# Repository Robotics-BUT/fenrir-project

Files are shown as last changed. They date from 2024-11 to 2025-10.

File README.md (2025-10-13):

# Fenrir Project - Universal Robotic Platform

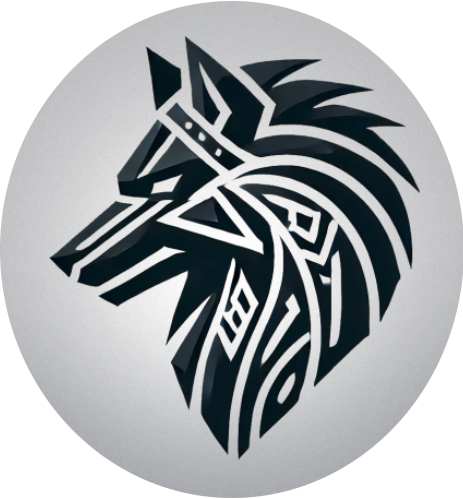
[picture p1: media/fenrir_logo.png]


The Fenrir Project is an open source of a multi purpose education robot dedicated for wide range of applications and usage in high-schools and universities.

The robot is based on Raspberry Pi 4 and Arduino Nano. The Raspberry Pi provides computational power, ROS2 support, WiFi connection and USB support. The Arduino Nano extends the PRi IOs and handles peripherals.

The development is currently still under development

## Robot Overview

### Robot visualization 

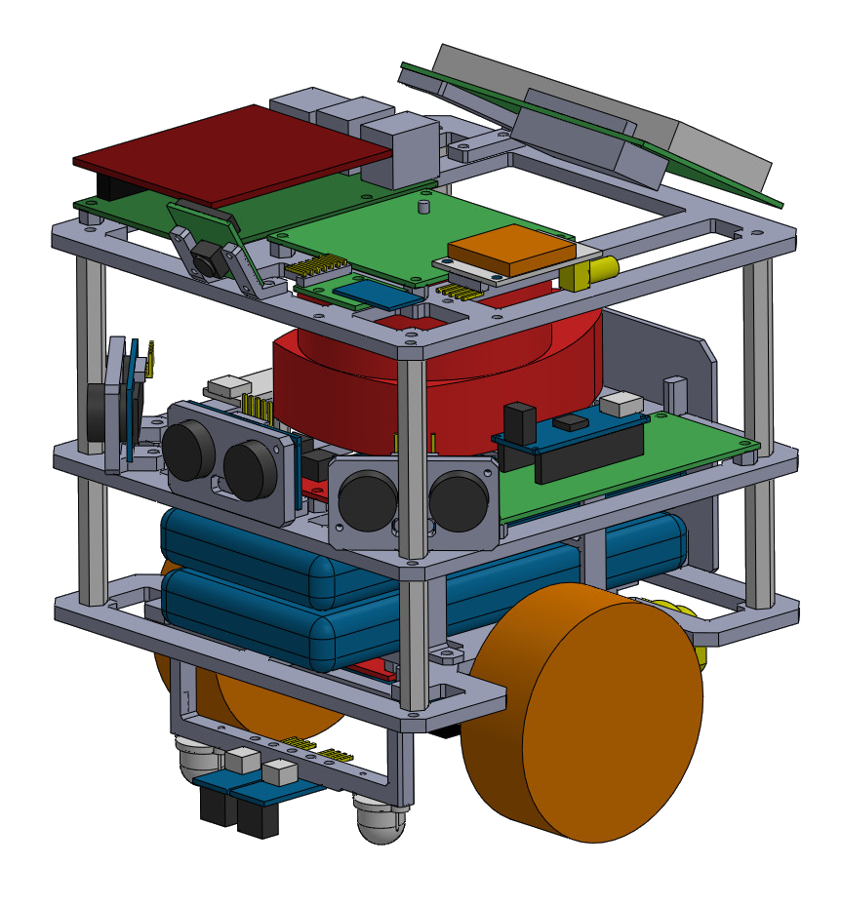
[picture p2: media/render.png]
Robot


### Overview schematic

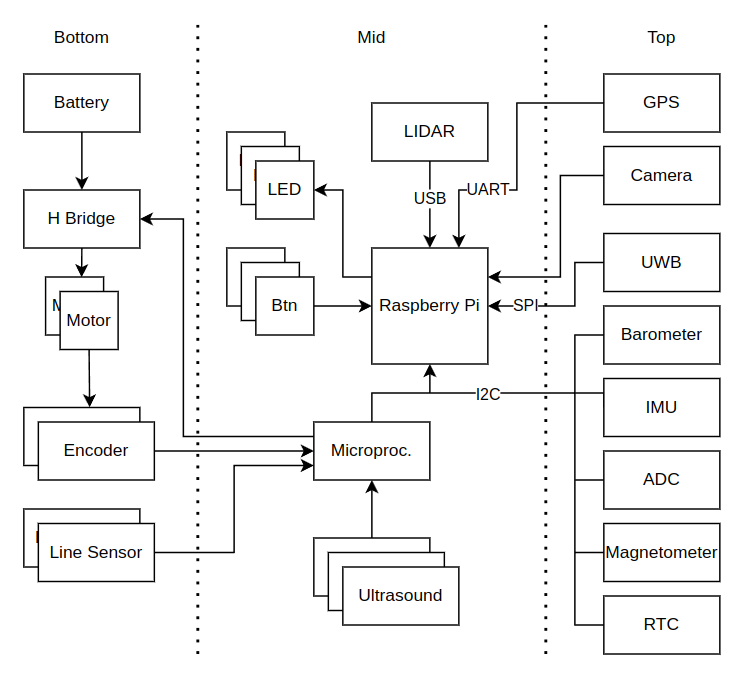
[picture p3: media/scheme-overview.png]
Overview schematic


### Power supply schematic

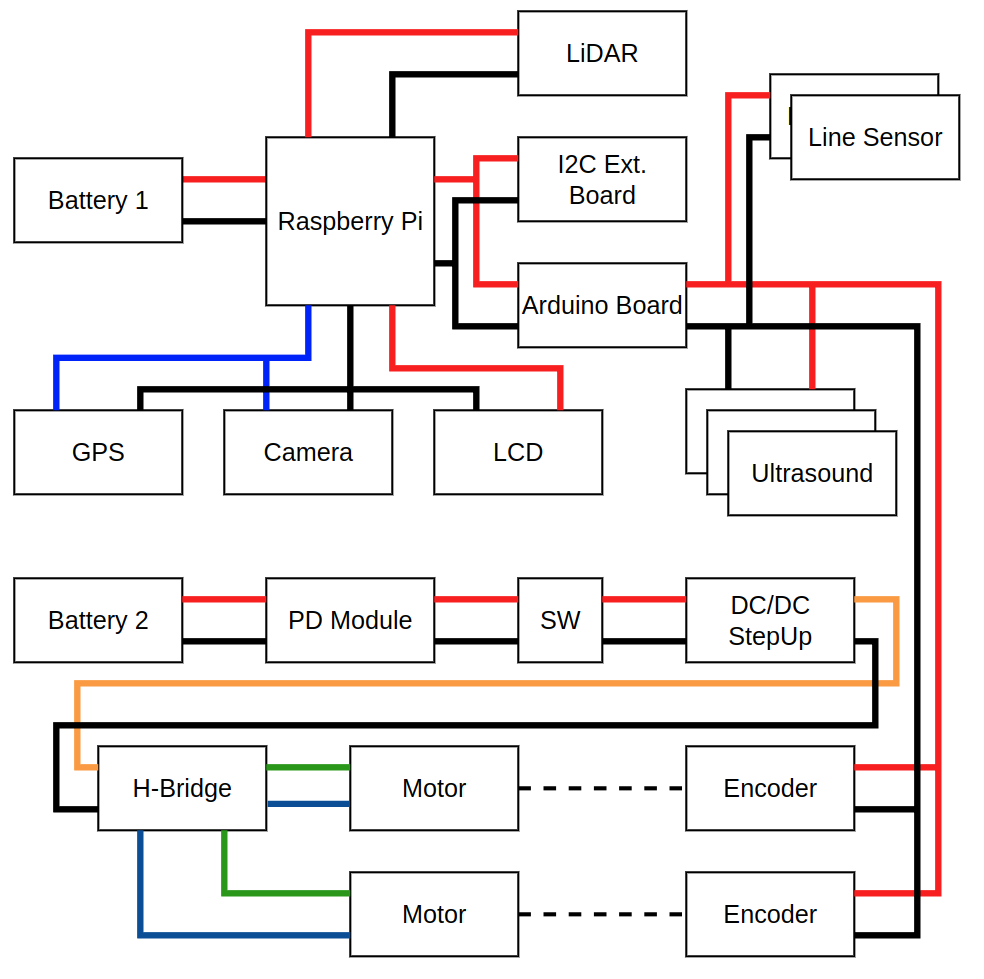
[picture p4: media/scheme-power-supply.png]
Power supply schematic


### Wiring Overview

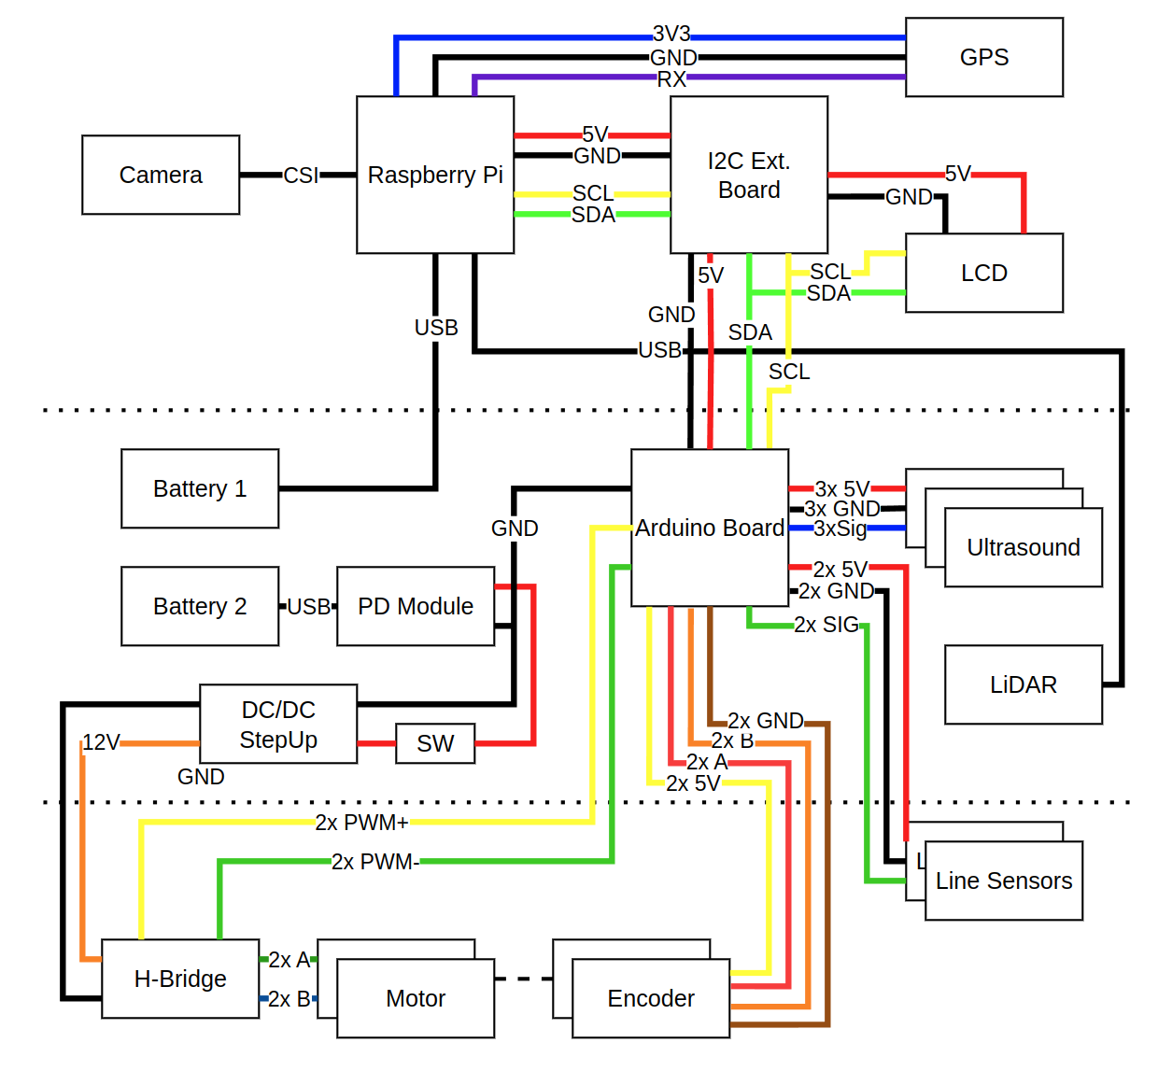
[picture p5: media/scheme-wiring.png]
Wiring Overview


**Note**: The sensors numbering goes from left to right
 - Ultrasound 1 - left, Ultrasound 2 - center, Ultrasound 3 - right
 - Line sensor 1 - left, Line sensor 2 - right
 - Motor 1 - left, Motor 2 - right
 - Encoder 1 - left, Encoder 2 - right

| **Module A** | **Pin**  | **Module B** | **Pin** | **Type** | **Length** | **Note** |
|---|---|---|---|---|---|---|
| Battery 1 | - | PD Module | - | USB-C - USB-C | 15cm | - |
| Battery 2 | - | Raspberry Pi | - | USB-C - USB-C | 15cm | - |
| Raspberry Pi | - | Camera | - | CSI Cable | 10cm | - |
| Raspberry Pi | 3v3 | GPS | VCC | wire (blue) | 10cm | 3V3 |
| Raspberry Pi | GND | GPS | GND | wire (black) | 10cm | GND |
| Raspberry Pi | Rx | GPS | TxD | wire (purple) | 10cm | UART |
| Raspberry Pi | 5V | I2C Board | 5V | wire (red) | 8cm | 5V |
| Raspberry Pi | GND | I2C Board | GND | wire (black) | 8cm | GND |
| Raspberry Pi | SCL | I2C Board | SCL | wire (yellow) | 8cm | SCL |
| Raspberry Pi | SDA | I2C Board | SDA | wire (green) | 8cm | SDA |
| Raspberry Pi | - | LIDAR | - | USB-A - microUSB | 10cm | - |
| I2C Board | 5V | LCD | VCC | wire (red) | 8cm | 5V |
| I2C Board | GND | LCD | GND | wire (black) | 8cm | GND |
| I2C Board | SCL | LCD | SCL | wire (yellow) | 8cm | SCL |
| I2C Board | SDA | LCD | SDA | wire (green) | 8cm | SDA |
| I2C Board | 5V | Arduino | VCC | wire (red) | 15cm | 5V |
| I2C Board | GND | Arduino | GND | wire (black) | 15cm | GND |
| I2C Board | SCL | Arduino | SCL | wire (yellow) | 15cm | SCL |
| I2C Board | SDA | Arduino | SDA | wire (green) | 15cm | SDA |
| Arduino | US1 | Ultrasound 1 | Vcc | wire (red) | 10cm | 5V |
| Arduino | US1 | Ultrasound 1 | GND | wire (black) | 10cm | GND |
| Arduino | US1 | Ultrasound 1 | Echo/Trig | wire (blue) | 10cm | signal |
| Arduino | US2 | Ultrasound 2 | Vcc | wire (red) | 10cm | 5V |
| Arduino | US2 | Ultrasound 2 | GND | wire (black) | 10cm | GND |
| Arduino | US2 | Ultrasound 2 | Echo/Trig | wire (blue) | 10cm | signal |
| Arduino | US3 | Ultrasound 3 | Vcc | wire (red) | 15cm | 5V |
| Arduino | US3 | Ultrasound 3 | GND | wire (black) | 15cm | GND |
| Arduino | US3 | Ultrasound 3 | Echo/Trig | wire (blue) | 15cm | signal |
| Arduino | Line1 | Line Sens. 1 | VCC | wire (red) | 15cm | 5V |
| Arduino | Line1 | Line Sens. 1 | GND | wire (black) | 15cm | GND |
| Arduino | Line1 | Line Sens. 1 | A0 | wire (blue) | 15cm | signal |
| Arduino | Line2 | Line Sens. 2 | VCC | wire (red) | 15cm | 5V |
| Arduino | Line2 | Line Sens. 2 | GND | wire (black) | 15cm | GND |
| Arduino | Line2 | Line Sens. 2 | A0 | wire (blue) | 15cm | signal |
| Arduino | 5V | Encoder 1 | - | wire (yellow) | 20cm | 5V |
| Arduino | GND | Encoder 1 | - | wire (brown) | 20cm | GND |
| Arduino | EN1A | Encoder 1 | - | wire (red) | 20cm | A |
| Arduino | EN1B | Encoder 1 | - | wire (orange) | 20cm | B |
| Arduino | 5V | Encoder 2 | - | wire (yellow) | 20cm | 5V |
| Arduino | GND | Encoder 2 | - | wire (brown) | 20cm | GND |
| Arduino | EN2A | Encoder 2 | - | wire (red) | 20cm | A |
| Arduino | EN2B | Encoder 2 | - | wire (orange) | 20cm | B |
| Arduino | GND | PD Module | OUT- | wire (black) | - | - |
| Arduino | M1A | H-Bridge | IN3 | wire (yellow) | 20cm | PWM A+ |
| Arduino | M1B | H-Bridge | IN4 | wire (green) | 20cm | PWM A- |
| Arduino | M2A | H-Bridge | IN1 | wire (yellow) | 20cm | PWM B+ |
| Arduino | M2B | H-Bridge | IN2 | wire (green) | 20cm | PWM B- |
| PD Module | + | H-Bridge | +12V | wire (orange) | 15cm | 12V |
| PD Module | - | H-Bridge | GND | wire (black) | 15cm | GND |
| H-Bridge | OUT1+ | Motor 1 | - | wire (green) | 20cm | + |
| H-Bridge | OUT1- | Motor 1 | - | wire (blue) | 20cm | - |
| H-Bridge | OUT2+ | Motor 2 | - | wire (green) | 20cm | + |
| H-Bridge | OUT2- | Motor 2 | - | wire (blue) | 20cm | - |

## Equipment

| Role | Component | URL |
|---|---|---|
| Main Computer | RPi | [link](https://cz.mouser.com/ProductDetail/Raspberry-Pi/SC01959?qs=T%252BzbugeAwjhNCW2QVhlotw%3D%3D) |
| Helper Microcontroller | Arduino Nano | [link](https://www.laskakit.cz/arduino-nano-r3--atmega328p-klon--pripajene-piny/) |
| 2x Battery | Powerbank 10000 mAh | [link](https://www.alza.cz/alzapower-parade-power-delivery?dq=7177723) |
| Camera | RPi Camera v2 | [link](https://rpishop.cz/mipi-kamerove-moduly/329-raspberry-pi-kamera-modul-v2.html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) |
| GPS | NEO-7M module | [link](https://dratek.cz/arduino/1733-gps-satelitni-urceni-polohy-neo-7m-modul.html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) |
| 2D LiDAR | RPLiDAR A1M8 | [link](https://rpishop.cz/lidary/1631-rplidar-a1m8-360stupnovy-laserovy-scanner-kit-dosah-12m.html) |
| LCD | HD44780 20x4 I2C | [link](https://dratek.cz/arduino/1421-eses-i2c-20x4-display-pro-jednodeskove-pocitace.html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) |
| 3x Ultrasound | SRF-05 | [link](https://dratek.cz/arduino/1735-meric-vzdalenosti-ultrazvukovy-5pin-hy-srf05-pro-arduino.html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) |
| 2x Line Sensor | TCRT5000 module | [link](https://www.laskakit.cz/arduino-infracerveny-senzor-sledovani-cary-s-lm393/) |
| H Bridge | L298N module | [link](https://www.laskakit.cz/h-mustek-pro-krokovy-motor-l298n--dualni-motorovy-modul/) |
| Motor with Encoder | DG01D‐E | [link](https://cz.mouser.com/ProductDetail/SparkFun/ROB-16413?qs=vmHwEFxEFR%2F20T1Ah9zr5w%3D%3D) |
| IMU | MPU6050 | [link](https://pajenicko.cz/gyroskop-akcelerometr-gy-521-s-mpu6050-i2c) |
| Barometer | BME280 | [link](https://pajenicko.cz/senzor-na-mereni-teploty-vlhkosti-tlaku-bme280) |
| Real Time Clock | DS3231 | [link](https://www.laskakit.cz/arduino-rtc-hodiny-realneho-casu-ds3231-at24c32/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) |
| ADC | ADS1115 | [link](https://pajenicko.cz/ad-prevodnik-ads1115-s-programovatelnym-zesilenim-16bit-4-kanaly-i2c-rozhrani) |
| UWB (not yet) | DWM1000 | [link](https://www.laskakit.cz/decawave-dwm1000-lokalizacni-modul/) |
| DC/DC Step Up | XL6009 | [link](https://www.laskakit.cz/step-up-boost-menic-s-xl6009--cervena/) |
| Power Delivery | USB-C PD module | [link](https://www.laskakit.cz/usb-c-pd-qc-prepinac-napajeciho-napeti/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) |
| Switch | | [link](https://pajenicko.cz/kulaty-kolebkovy-spinac-se-zelenou-led-12v-20a) |

## Acknowledgments

This work was created with the support of project RP182401001 under the PPSŘ 2025 program.

## Authors

Adam Ligocki - adam.ligocki@vut.cz

Petr Šopák - petr.sopak@vut.cz

Jakum Minařík

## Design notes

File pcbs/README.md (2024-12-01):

# Fenrir Project - PCBs

### RPi Ext Board

Schema

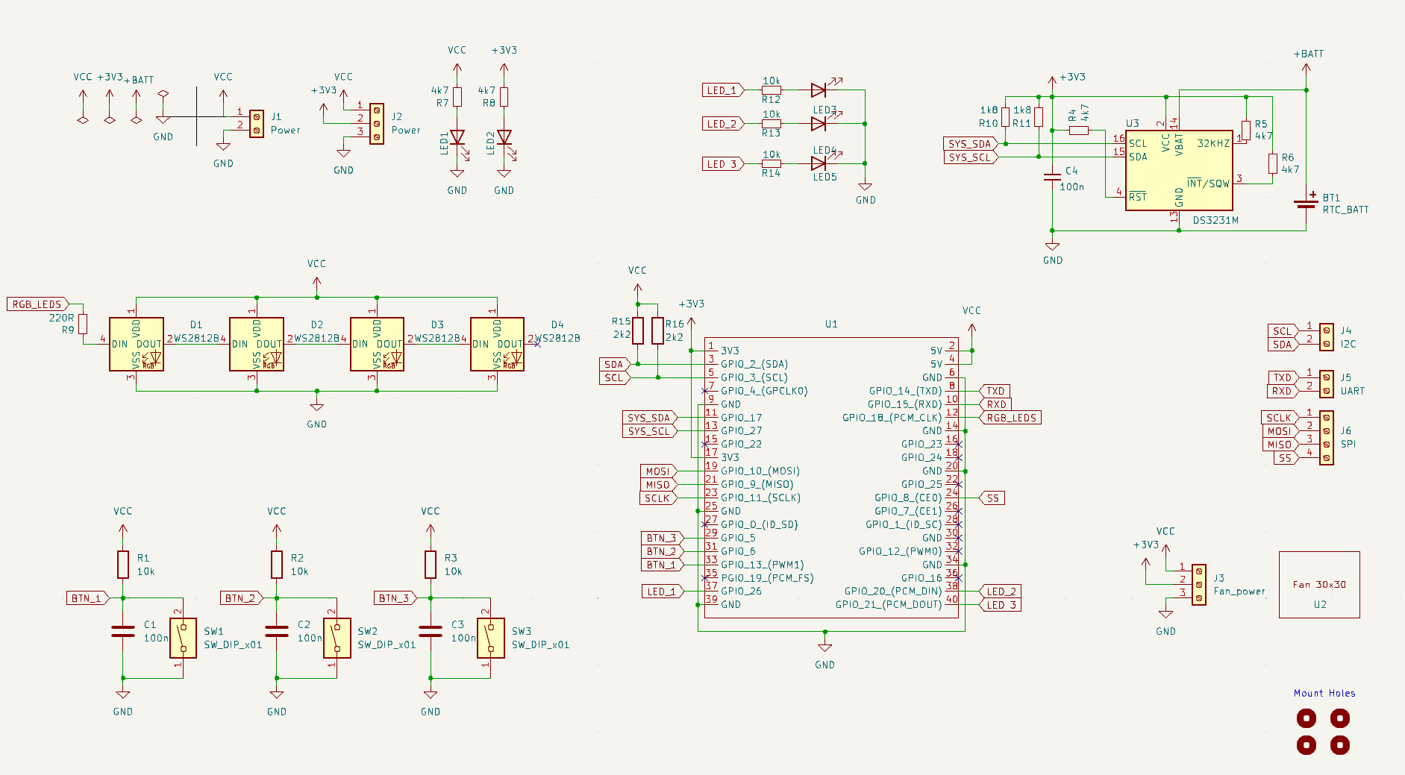
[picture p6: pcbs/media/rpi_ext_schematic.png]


Render Top

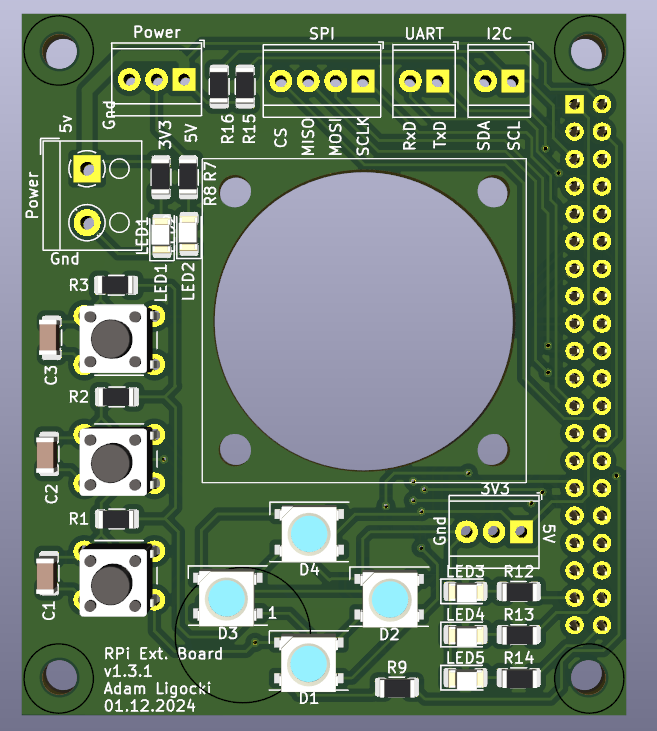
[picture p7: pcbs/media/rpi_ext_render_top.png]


Render Bot

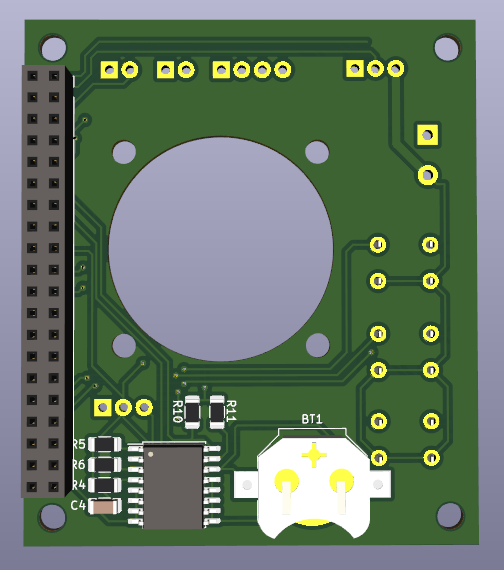
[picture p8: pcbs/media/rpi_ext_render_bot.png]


### Arduino Board

Schema

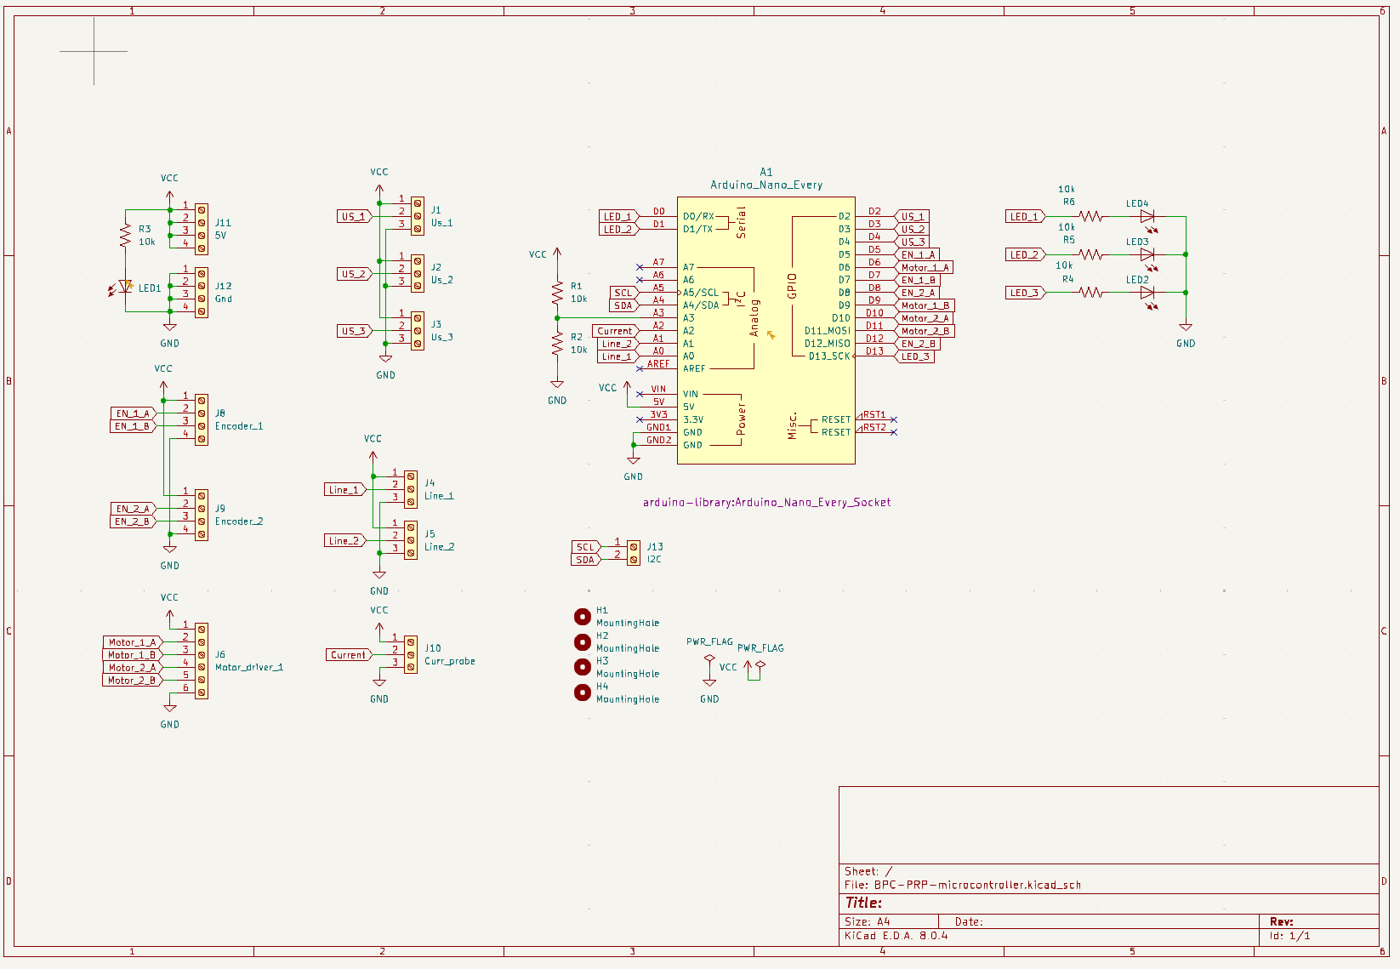
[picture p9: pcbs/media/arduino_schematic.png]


Render Top

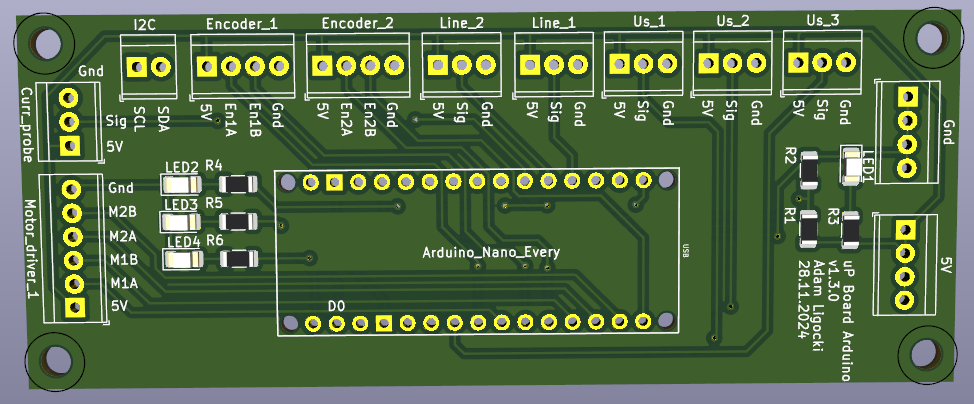
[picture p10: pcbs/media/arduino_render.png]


### I2C Board

Schema

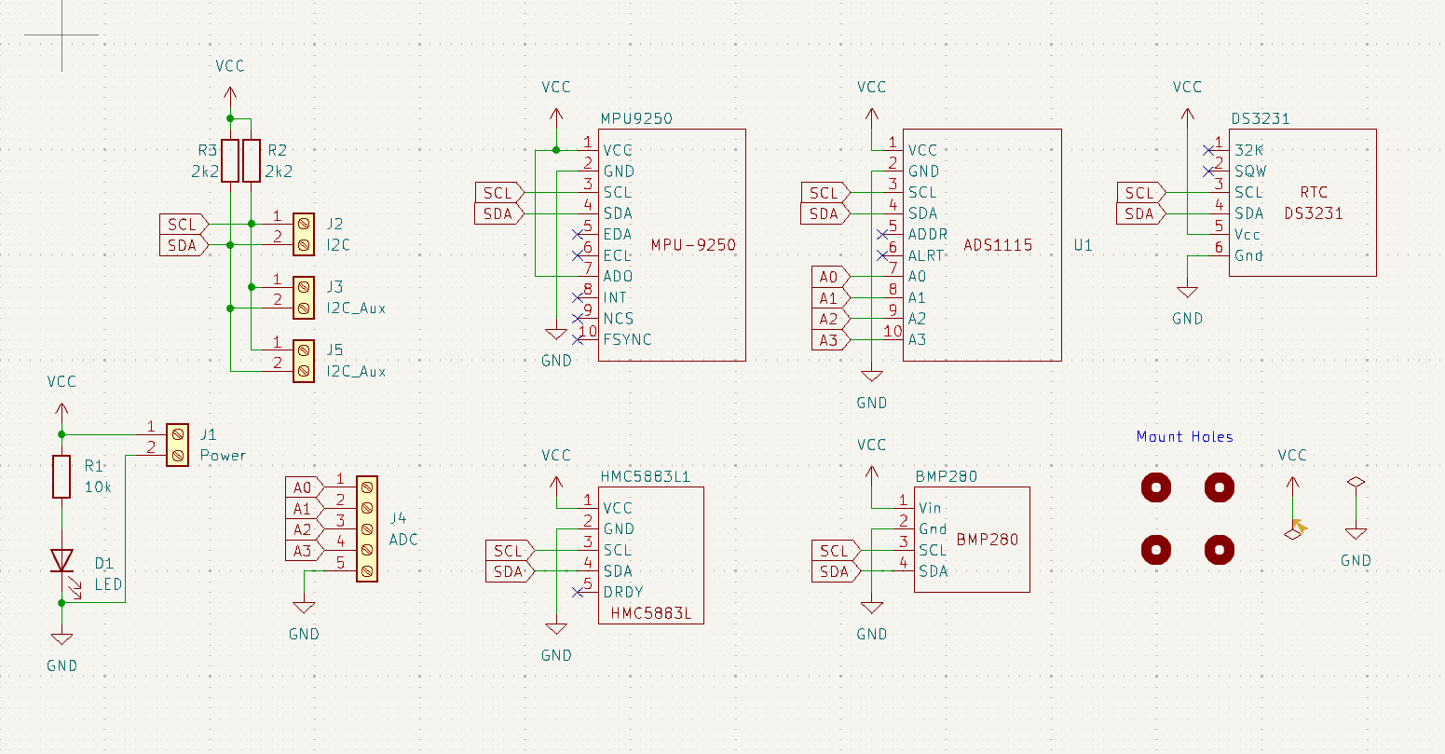
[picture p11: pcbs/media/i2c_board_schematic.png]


Render Top

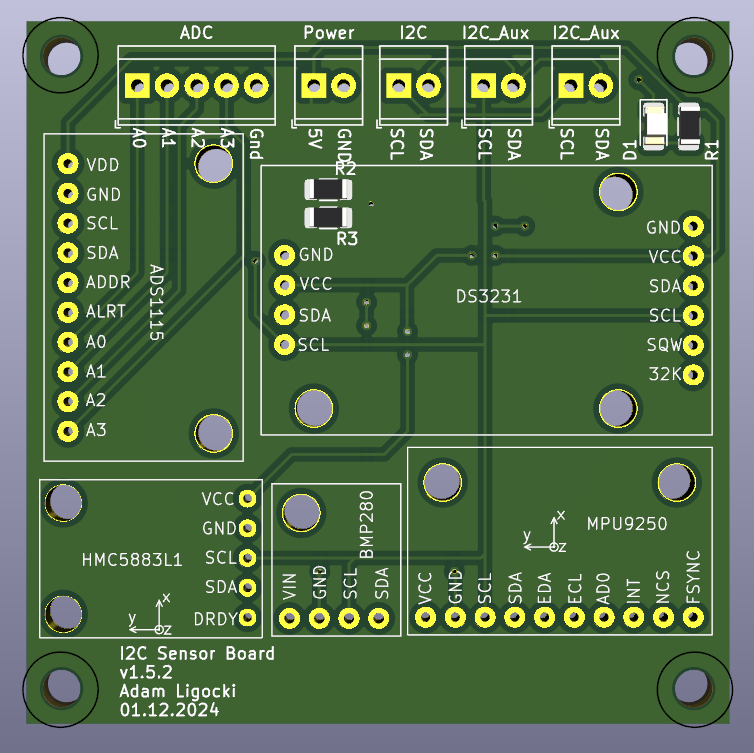
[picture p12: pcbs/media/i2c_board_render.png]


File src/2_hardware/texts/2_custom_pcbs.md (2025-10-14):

# Custom PCBs

This chapter presents the custom PCBs designed for the Fenrir Project.

The robot includes **three custom PCBs** with the following functionalities:

 - **Raspberry Pi Sield (header)**
   - Power supply
   - I2C bus
   - SPI bus
   - UART bus
   - Fan cooling
   - Buttons
   - LEDs

 - **I2C Sensor Board**
   - IMU (Accelerometer + Gyroscope)
   - Barometer
   - Magnetometer
   - ADC
   - Real-Time Clock (RTC)

 - **Arduino Nano Board**
   - I2C bus
   - Motor Control
   - Motor Encoders
   - Ultrasonic Sensors
   - Line Sensors

For detailed design files, please refer to the [`pcbs folder`](/pcbs) in the root of this repository.

------------------------------------------------------------------------------------------------------------
### Raspberry Pi Shield

<p id="rpi_ext_schematic" align="center">
  ext_schematic
</p align="center">
<p align="center"><em>Figure 1. Raspberry Pi Shield schematic.</em></p>

<p id="rpi_ext_render_top" align="center">
  rpi_ext_render_top
</p align="center">
<p align="center"><em>Figure 2. Raspberry Pi Shield 3D render.</em></p>

### I2C Sensor Board

<p id="i2c_board_schematic" align="center">
  i2c_board_schematic
</p align="center">
<p align="center"><em>Figure 3. I2C Sensor Board schematic.</em></p>

<p id="i2c_board_render" align="center">
  i2c_board_render
</p align="center">
<p align="center"><em>Figure 4. I2C Sensor Board 3D render.</em></p>

### Arduino Nano Every Board

<p id="arduino_schematic" align="center">
  arduino_schematic
</p align="center">
<p align="center"><em>Figure 5. Arduino Nano Board schematic.</em></p>

<p id="arduino_render" align="center">
  arduino_render
</p align="center">
<p align="center"><em>Figure 6. Arduino Nano Board 3D render.</em></p>

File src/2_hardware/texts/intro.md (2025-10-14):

# Hardware Desing

This section provides a detailed description of all hardware components required to build the robot.  
It covers 3D-printed parts, electronic components, integrated modules, and custom-designed PCBs.

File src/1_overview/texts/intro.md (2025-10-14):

# Fenrir Project Overview

<p id="fenrir_logo" align="center">
  Fenrir Logo
</p align="center">

The **Fenrir Project** is an open-source, multi-purpose educational robot designed for a wide range of applications in high schools and universities.

The robot is based on *Raspberry Pi 4* and *Arduino Nano*. The Raspberry Pi provides computational power, ROS2 support, WiFi connection and USB support. The Arduino Nano extends the Raspberry Pi IOs and manages peripherals.

## Robot Overview

### Visualization - Physical Design

<p id="robot_renderer" align="center">
  robot renderer
</p align="center">

### Schematic system Architecture

<p id="overview_schematic" align="center">
  Overview schematic
</p align="center">

## Acknowledgments

This work was created with the support of project RP182401001 under the PPSŘ 2025 program.

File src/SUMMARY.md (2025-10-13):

[Introduction](title-page.md)

- [Fenrir Project Overview](1_overview/texts/intro.md)
- [Hardware Design](2_hardware/texts/intro.md)
  - [3D Print](2_hardware/texts/1_3d_print.md)
  - [Custom PCBs](2_hardware/texts/2_custom_pcbs.md)
  - [Modules](2_hardware/texts/3_modules.md)
  - [Wiring](2_hardware/texts/4_wirings.md)
  - [Bill of Materials](2_hardware/texts/5_bom.md)
- [Software Architecture](3_software/texts/intro.md)
  - [Raspberry Pi Software](3_software/texts/1_rpi_sw.md)
  - [Arduino Firmware](3_software/texts/2_arduino_fw.md)
- [Robot Assembly](4_assembly/texts/intro.md)
    - [Assembly - step by step](4_assembly/texts/assembly.md)
- [SW Installation and Setup](5_setup/texts/intro.md)
    - [Raspberry Pi Installation](5_setup/texts/1_rpi.md)
    - [Arduino Programming](5_setup/texts/2_arduino.md)

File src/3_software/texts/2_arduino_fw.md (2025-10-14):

# Arduino Firmware

The firmware is available here Firmware.

This Arduino Nano program works as a motor controller that talks with a main computer (for example a Raspberry Pi) using I2C communication. The Nano is an I2C slave – it waits for messages from the master and answers when needed. When the master sends data, the Nano updates target speeds or control settings. When the master asks for data, the Nano sends back measurements like encoder counts or wheel speeds. This communication happens using interrupt callbacks, so it does not stop the main program loop. In this way, the Nano can control motors and communicate at the same time.

Arduino handles the ultrasound sensors, line sensors, possible extension for current sensor and controls the motors.

The robot wheels have encoders that measure how fast they rotate. Each encoder gives electrical pulses when the wheel moves. The Nano uses interrupts to count these pulses very quickly without missing them. The number of pulses in a short time tells how fast the wheel is turning. In the main loop, the program reads these counts and calculates the wheel speed. These measured speeds are compared with the target speeds received from the master to see if the motors are running correctly or need adjustment.

To keep the wheels turning at the right speed, the Nano uses a PID controller. In every cycle of the main loop, the program calculates the difference between target and actual speed and adjusts the motor power with PWM signals. The direction pins control forward or backward rotation, and the PWM value sets how strong the motor runs. The main loop repeats this many times per second, keeping the movement smooth and stable. Meanwhile, I2C and encoder interrupts work in the background, so the system always knows the latest speed and can react quickly to commands from the master.

## Memory Space

<div align = center>

| Byte | Value | Length | R/W |
|---|---|---|-----|
| 0 | ultrasound 0 distance [cm] | 1B | R |
| 1 | ultrasound 1 distance [cm] | 1B | R |
| 2 | ultrasound 2 distance [cm] | 1B | R |
| 3 | encoder A [-] | 4B | R |
| 7 | encoder B [-] | 4B | R |
| 11 | current probe [-] | 2B | R |
| 13 | line sensor 0 [-] | 2B | R |
| 15 | line sensor 1 [-] | 2B | R |
| 17 | motor 0 speed [-] | 2B | W |
| 18 | motor 1 speed [cm] | 1B | W |
| 19 | reserverd | 1B | - |

</div>

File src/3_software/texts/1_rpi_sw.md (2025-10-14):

# Raspberry Pi Software

This project runs on a Raspberry Pi (Ubuntu + ROS 2 Humble) and acts as the high-level HW wrapper of the robot. The Pi hosts ROS 2 nodes that handle lidar, camera, I2C sensors (and the Arduino), RGB LEDs, and buttons. In effect, it gathers all the sensory data, publish them via ROS 2 topics, which makes it easy to read and make decisions and later on it accepts topic for motor speeds.

For sensors, the Pi runs specialized ROS 2 nodes: one for the lidar to scan the environment, one for the camera to capture images or video, and drivers for I2C sensors (ADC, IMU, magnetometer, etc.) and the Arduino (which itself controls motors and encoders, line sensors and ultrasounds). There are also nodes (or scripts) to manage RGB LEDs (for status or feedback) and buttons (for user interaction or emergency stop). All sensor inputs are published into the ROS 2 ecosystem so other nodes (e.g. navigation, mapping, control) can subscribe and act on them.

In addition, the repository includes helper scripts for setting up the Raspberry Pi environment (installing required packages, configuring ROS 2, setting up node launch files, calibrations, etc.). These scripts make it easier to initialize a fresh Pi with all dependencies, and to launch the full ROS 2 system smoothly. So overall, the Raspberry Pi side is responsible for integrating sensors, executing high-level logic, and coordinating with the Arduino via I2C, all within the ROS 2 framework on Ubuntu.

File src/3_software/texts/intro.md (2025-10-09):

# Software Architecture

This chapter discusses software architecture of the Fenrir Robot.

The Raspberry Pi software and the Arduino firmware is described and the way how both systems communicate with each other.

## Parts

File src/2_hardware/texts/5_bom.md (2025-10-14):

# Bill of Materials

<div align="center">

| Role | Quantity | Price pre one | URL |
|---|---|---|---|
| RPi 4 4GB | 1 | 60 EUR | [link](https://cz.mouser.com/ProductDetail/Raspberry-Pi/SC01959?qs=T%252BzbugeAwjhNCW2QVhlotw%3D%3D) |
| RPLidar | 1 | 130 EUR | [link](https://rpishop.cz/lidary/1631-rplidar-a1m8-360stupnovy-laserovy-scanner-kit-dosah-12m.html) |
| SD Card 32GB | 1 | 12 EUR | [link](https://rpishop.cz/micro-sd/3132-raspberry-pi-32gb-microsdhc-class-10-uhs-i-u1-a1-s-raspberry-pi-os.html) |
| RPi Camera v2 | 1 | 18 EUR | [link](https://rpishop.cz/mipi-kamerove-moduly/329-raspberry-pi-kamera-modul-v2.html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) |
| RPi Cooling | 1 | 2 EUR | [link](https://rpishop.cz/pasivni/669-hlinikove-chladice-pro-raspberry-pi.html) |
| RPi Fan | 1 | 3 EUR | [link](https://rpishop.cz/aktivni/1644-vetrak-pro-raspberry-pi-30cm-kabel.html) |
| | | | |
| DC Motor | 2 | 12 EUR | [link](https://cz.mouser.com/ProductDetail/SparkFun/ROB-16413?qs=vmHwEFxEFR%2F20T1Ah9zr5w%3D%3D) |
| | | | |
| Arduino Every | 1 | 15 EUR | [link](https://www.laskakit.cz/arduino-nano-every--original/) |
| Line Sensor | 2 | 1 EUR | [link](https://www.laskakit.cz/arduino-infracerveny-senzor-sledovani-cary-s-lm393/) |
| H-Bridge | 1 | 2 EUR | [link](https://www.laskakit.cz/h-mustek-pro-krokovy-motor-l298n--dualni-motorovy-modul/) |
| MPU6500 | 1 | 3 EUR | [link](https://www.laskakit.cz/arduino-gyroskop-a-akcelerometr-gy-521--mpu6050/) |
| HMC5883L | 1 | 3 EUR | [link](https://www.laskakit.cz/3-osy-magnetometr-a-kompas-hmc5883l/) |
| DC/DC step up | 1 | 2 EUR | [link](https://dratek.cz/arduino/1752-boost-buck-step-up-down-modul-solarniho-napajeni-nastavitelny-dc-dc-xl6009.html) |
| SRF05 | 3 | 2 EUR | [link](https://dratek.cz/arduino/1735-meric-vzdalenosti-ultrazvukovy-5pin-hy-srf05-pro-arduino.html) |
| RTC | 1 | 4 EUR | [link](https://dratek.cz/arduino/1261-rtc-hodiny-realneho-casu-ds3231-at24c32-iic-pametovy-modul-pro-arduino.html) |
| ADS1115 | 1 | 15 EUR | [link](https://dratek.cz/arduino/2955-i2c-ad-prevodnik-ads1115-16-bit-adc-4-kanaly-s-programovatelnym-zesilenim.html) |
| BME280 | 1 | 8 EUR | [link](https://dratek.cz/arduino/1361-bme280-modul-mereni-teploty-vlhkosti-a-barometrickeho-tlaku-precizni.html) |
| | | | |
| USB PD Module | 1 | 2 EUR | [link](https://www.laskakit.cz/usb-c-pd-qc-prepinac-napajeciho-napeti/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) |
| | | | |
| LCD | | | |
| | | | |
| Screw terminal 2x 5.08 | 5 | 0.3 EUR | [link](https://www.laskakit.cz/sroubovaci-svorkovnice-do-dps-kf301-2p/) |
| Screw terminal 3x 2.54 | 8 | 0.3 EUR | [link](https://www.laskakit.cz/sroubovaci-svorkovnice-do-dps-kf128-2-54/?variantId=8868) |
| Screw terminal 2x 2.54 | 5 | 0.2 EUR | |
| | | | |
| GPS | 1 (optional) | 15 EUR | [link](https://dratek.cz/arduino-platforma/1733-gps-satelitni-urceni-polohy-neo-7m-modul.html) |
| DWM 1000 | 1 (optional) | 40 EUR | [link](https://cz.mouser.com/ProductDetail/Qorvo/DWM1000?qs=sGAEpiMZZMu3sxpa5v1qrrjDD2pjKdCcRPXEFIZh8rA%3D) |
| | | | |
| Powerbank | 2 | 20 EUR | [link](https://www.alza.cz/alzapower-parade-power-delivery?dq=7177721) |
| | | | |
| Caster | 3 | 3 EUR | [link](https://botland.store/reference-balls/137-ball-caster-12-metal-pololu-953-5903351240772.html) |
| | | | |
| Screw M3x6 | 44 | - | - |
| Screw M3x25 | 4 | - | - |
| | | | |
| Color Wires | - | - | - |
</div>

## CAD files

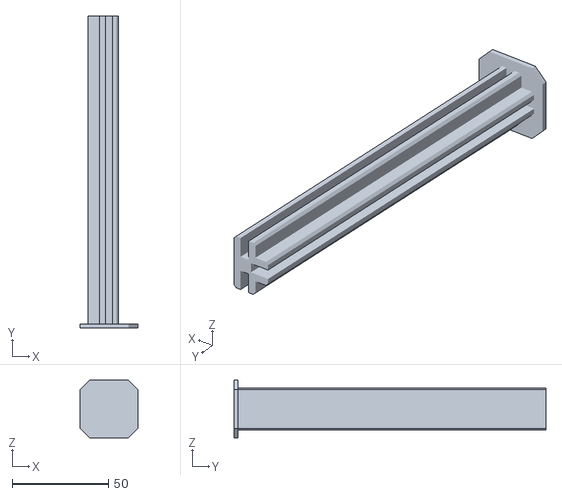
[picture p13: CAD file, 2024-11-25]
3d-print/maze/joint_3.STL
30.0 x 162.0 x 30.0

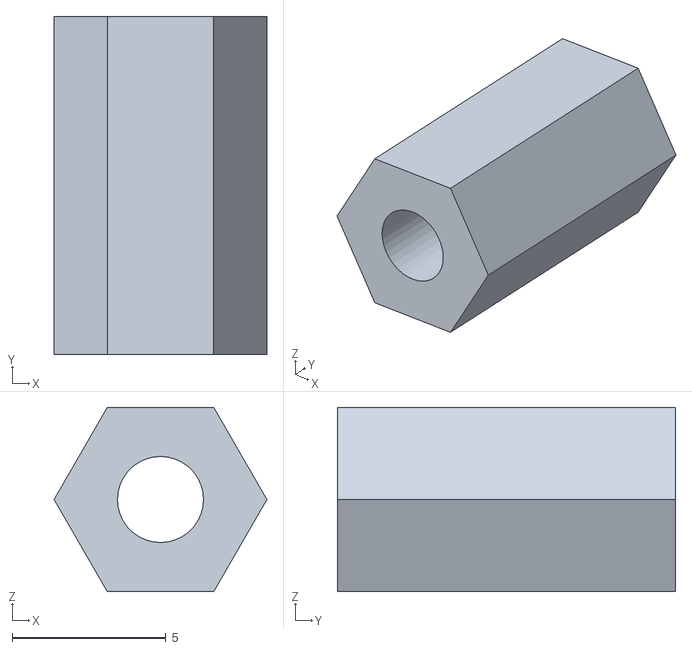
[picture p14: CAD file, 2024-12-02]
3d-print/robot/pillar.STL
6.93 x 11.0 x 6.00

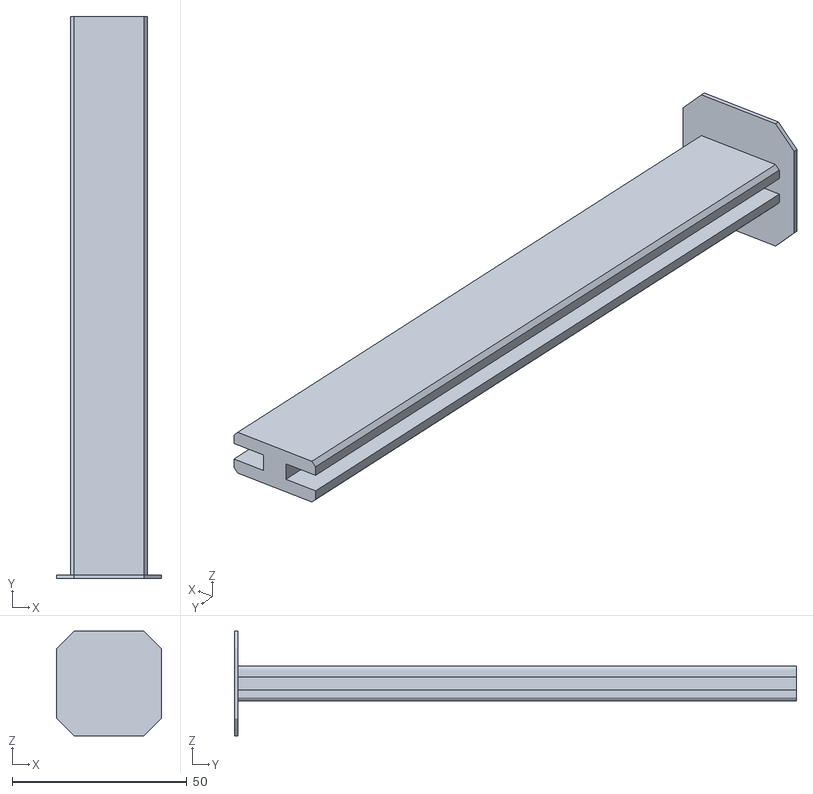
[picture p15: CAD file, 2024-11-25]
3d-print/maze/joint_2_180.STL
30.0 x 161.0 x 30.0

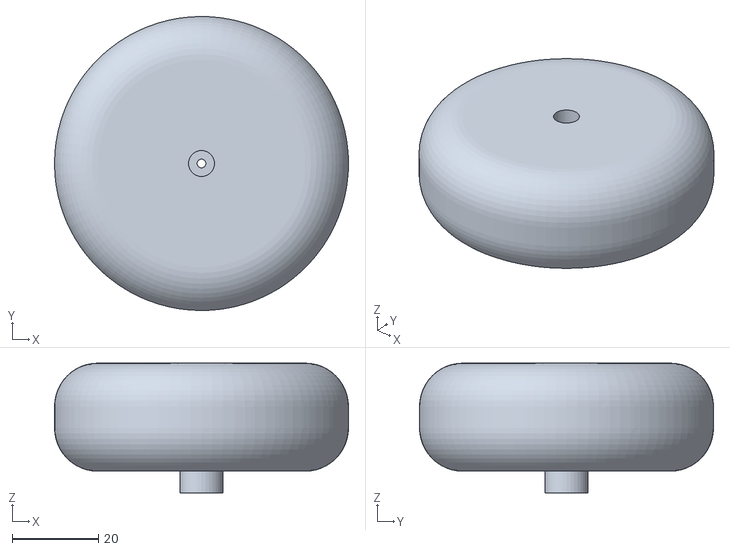
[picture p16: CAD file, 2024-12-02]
3d-print/robot/wheel.STL
68.0 x 68.0 x 30.0

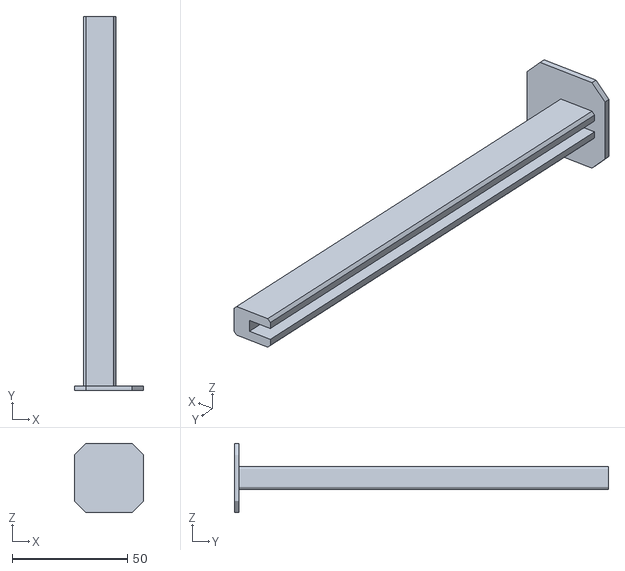
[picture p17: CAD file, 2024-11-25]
3d-print/maze/joint_1.STL
30.0 x 162.0 x 30.0

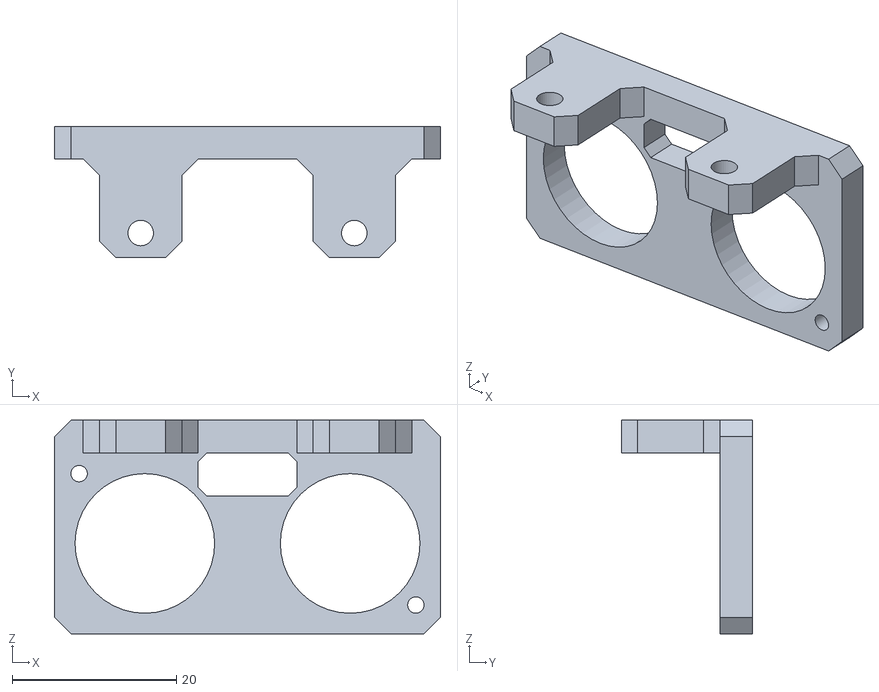
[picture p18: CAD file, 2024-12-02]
3d-print/robot/srf05_mount.STL
47.0 x 16.0 x 26.0

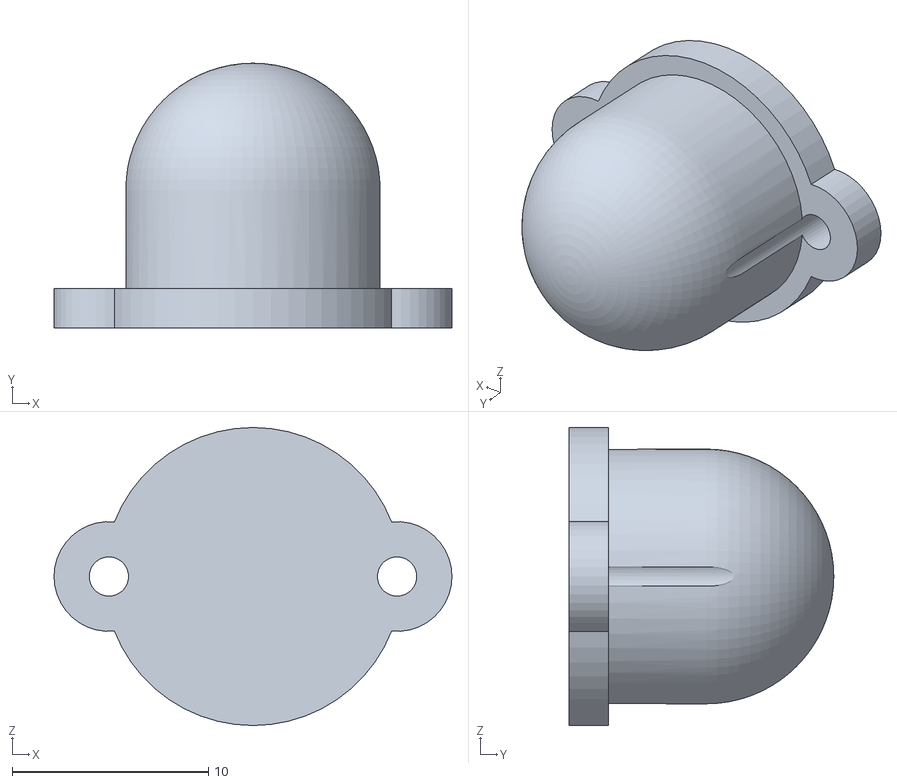
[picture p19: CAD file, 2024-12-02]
3d-print/robot/ball_2.STL
20.3 x 13.5 x 15.2

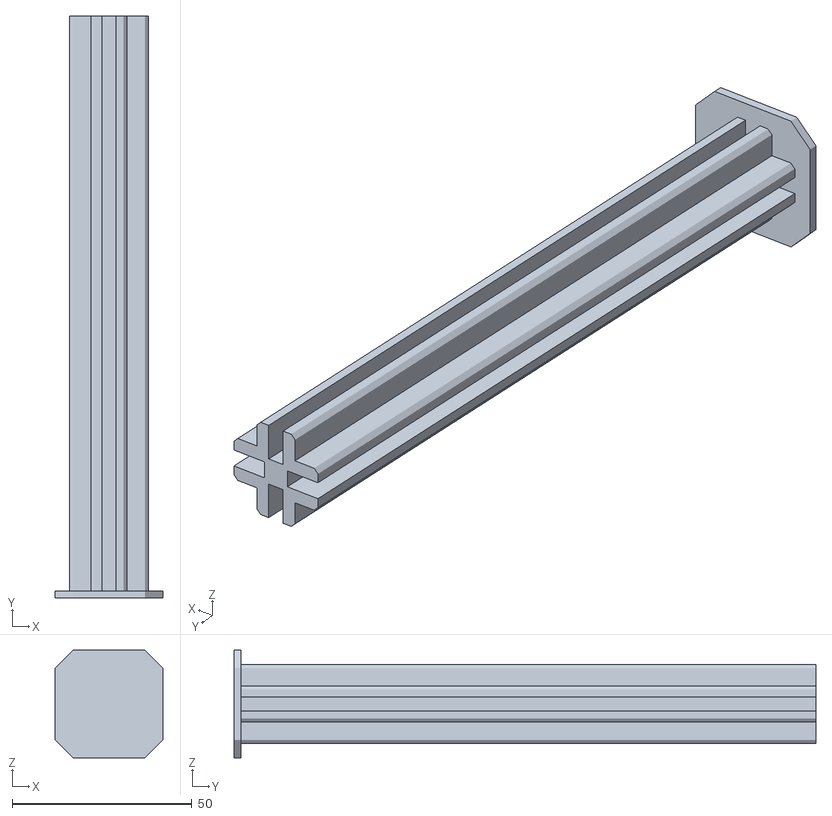
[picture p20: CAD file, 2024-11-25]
3d-print/maze/joint_4.STL
30.0 x 162.0 x 30.0

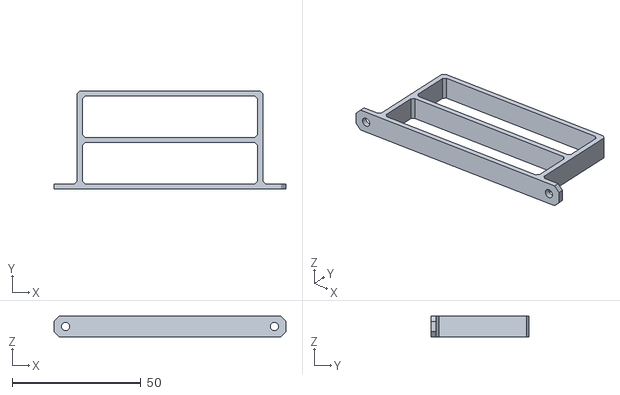
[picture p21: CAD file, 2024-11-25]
3d-print/robot/small_battery_mount.STL
90.0 x 38.0 x 8.00

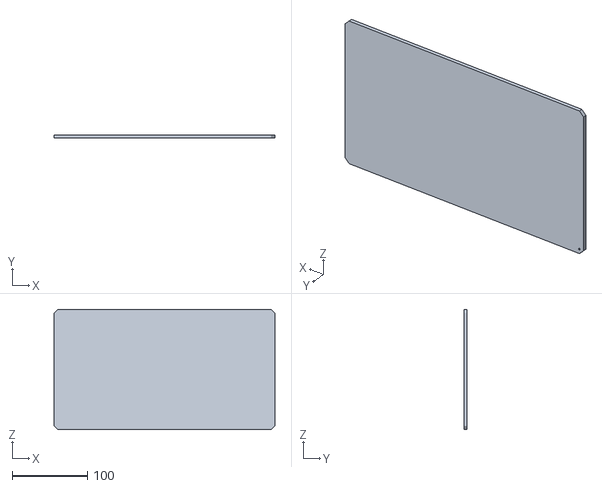
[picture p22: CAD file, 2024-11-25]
3d-print/maze/wall.STL
294.0 x 4.00 x 160.0

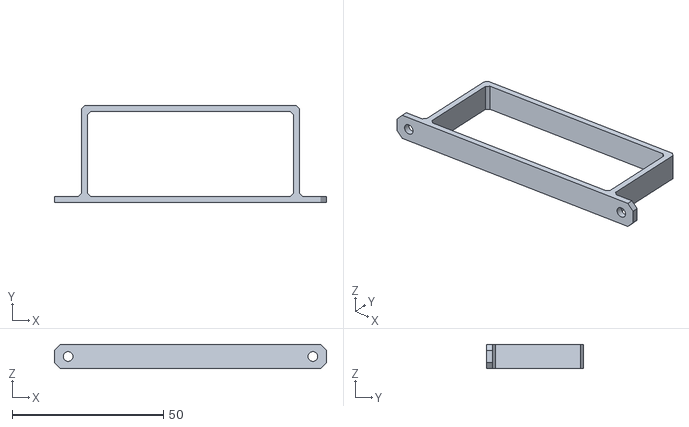
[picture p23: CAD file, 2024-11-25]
3d-print/robot/battery_mount.STL
90.0 x 32.0 x 8.00

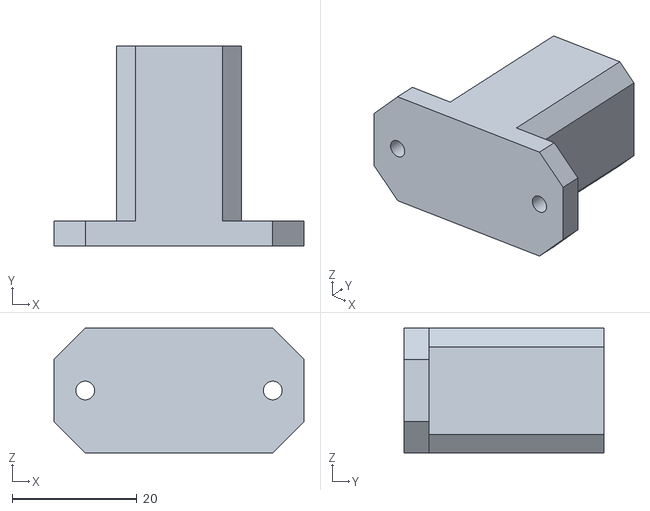
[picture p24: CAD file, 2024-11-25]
3d-print/robot/leg_rear_2.STL
40.0 x 32.0 x 20.0

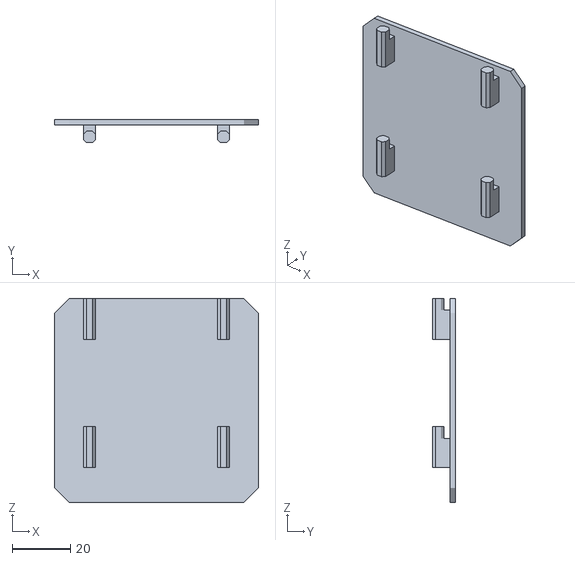
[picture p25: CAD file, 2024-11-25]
3d-print/robot/ar_tag_plate.STL
70.0 x 8.00 x 70.0

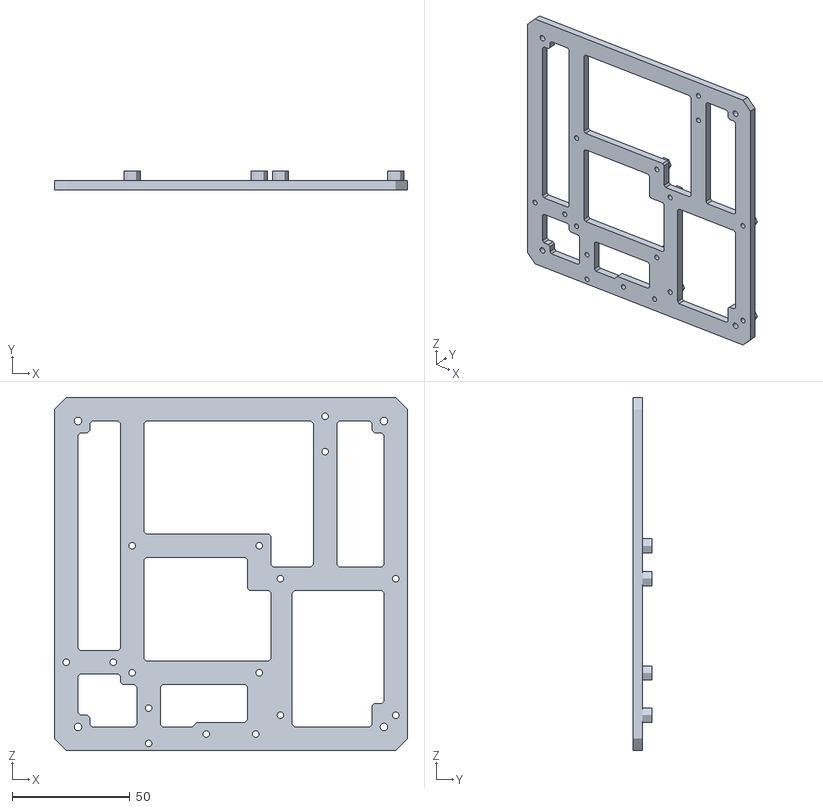
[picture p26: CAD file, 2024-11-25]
3d-print/robot/plate_top.STL
150.0 x 8.00 x 150.0

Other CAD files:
3d-print/maze/joint_2_90.STL
3d-print/robot/plate_bot.STL
3d-print/robot/plate_mid.STL
3d-print/robot/lcd_mount.STL
3d-print/robot/camera_mount.STL
3d-print/robot/leg_front_2.STL
3d-print/robot/stand.STL

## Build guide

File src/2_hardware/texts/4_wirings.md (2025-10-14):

# Wiring

<p align="center">
  Wiring Overview
</p>
<p align="center"><em>Figure 1. Wiring overview of the Fenrir robot.</em></p>

------------------------------------------------------------------------------

**Note**: Sensor and motor numbering follows a left-to-right convention:
- **Ultrasounds 1** - left, Ultrasound 2 - center, Ultrasound 3 - right
- **Line sensors:** 1 - left, Line sensor 2 - right
- **Motors:** 1 - left, Motor 2 - right
- **Encoders:** 1 - left, Encoder 2 - right

---------------------------------------------------------------------------------

<div align="center">
  
| **Module A** | **Pin**  | **Module B** | **Pin** | **Type** | **Length** | **Note** |
|---|---|---|---|---|---|---|
| Battery 1 | - | PD Module | - | USB-C - USB-C | 15cm | - |
| Battery 2 | - | Raspberry Pi | - | USB-C - USB-C | 15cm | - |
| Raspberry Pi | - | Camera | - | CSI Cable | 10cm | - |
| Raspberry Pi | 3v3 | GPS | VCC | wire (blue) | 10cm | 3V3 |
| Raspberry Pi | GND | GPS | GND | wire (black) | 10cm | GND |
| Raspberry Pi | Rx | GPS | TxD | wire (purple) | 10cm | UART |
| Raspberry Pi | 5V | I2C Board | 5V | wire (red) | 8cm | 5V |
| Raspberry Pi | GND | I2C Board | GND | wire (black) | 8cm | GND |
| Raspberry Pi | SCL | I2C Board | SCL | wire (yellow) | 8cm | SCL |
| Raspberry Pi | SDA | I2C Board | SDA | wire (green) | 8cm | SDA |
| Raspberry Pi | - | LIDAR | - | USB-A - microUSB | 10cm | - |
| I2C Board | 5V | LCD | VCC | wire (red) | 8cm | 5V |
| I2C Board | GND | LCD | GND | wire (black) | 8cm | GND |
| I2C Board | SCL | LCD | SCL | wire (yellow) | 8cm | SCL |
| I2C Board | SDA | LCD | SDA | wire (green) | 8cm | SDA |
| I2C Board | 5V | Arduino | VCC | wire (red) | 15cm | 5V |
| I2C Board | GND | Arduino | GND | wire (black) | 15cm | GND |
| I2C Board | SCL | Arduino | SCL | wire (yellow) | 15cm | SCL |
| I2C Board | SDA | Arduino | SDA | wire (green) | 15cm | SDA |
| Arduino | US1 | Ultrasound 1 | Vcc | wire (red) | 10cm | 5V |
| Arduino | US1 | Ultrasound 1 | GND | wire (black) | 10cm | GND |
| Arduino | US1 | Ultrasound 1 | Echo/Trig | wire (blue) | 10cm | signal |
| Arduino | US2 | Ultrasound 2 | Vcc | wire (red) | 10cm | 5V |
| Arduino | US2 | Ultrasound 2 | GND | wire (black) | 10cm | GND |
| Arduino | US2 | Ultrasound 2 | Echo/Trig | wire (blue) | 10cm | signal |
| Arduino | US3 | Ultrasound 3 | Vcc | wire (red) | 15cm | 5V |
| Arduino | US3 | Ultrasound 3 | GND | wire (black) | 15cm | GND |
| Arduino | US3 | Ultrasound 3 | Echo/Trig | wire (blue) | 15cm | signal |
| Arduino | Line1 | Line Sens. 1 | VCC | wire (red) | 15cm | 5V |
| Arduino | Line1 | Line Sens. 1 | GND | wire (black) | 15cm | GND |
| Arduino | Line1 | Line Sens. 1 | A0 | wire (blue) | 15cm | signal |
| Arduino | Line2 | Line Sens. 2 | VCC | wire (red) | 15cm | 5V |
| Arduino | Line2 | Line Sens. 2 | GND | wire (black) | 15cm | GND |
| Arduino | Line2 | Line Sens. 2 | A0 | wire (blue) | 15cm | signal |
| Arduino | 5V | Encoder 1 | - | wire (yellow) | 20cm | 5V |
| Arduino | GND | Encoder 1 | - | wire (brown) | 20cm | GND |
| Arduino | EN1A | Encoder 1 | - | wire (red) | 20cm | A |
| Arduino | EN1B | Encoder 1 | - | wire (orange) | 20cm | B |
| Arduino | 5V | Encoder 2 | - | wire (yellow) | 20cm | 5V |
| Arduino | GND | Encoder 2 | - | wire (brown) | 20cm | GND |
| Arduino | EN2A | Encoder 2 | - | wire (red) | 20cm | A |
| Arduino | EN2B | Encoder 2 | - | wire (orange) | 20cm | B |
| Arduino | GND | PD Module | OUT- | wire (black) | - | - |
| Arduino | M1A | H-Bridge | IN3 | wire (yellow) | 20cm | PWM A+ |
| Arduino | M1B | H-Bridge | IN4 | wire (green) | 20cm | PWM A- |
| Arduino | M2A | H-Bridge | IN1 | wire (yellow) | 20cm | PWM B+ |
| Arduino | M2B | H-Bridge | IN2 | wire (green) | 20cm | PWM B- |
| PD Module | + | H-Bridge | +12V | wire (orange) | 15cm | 12V |
| PD Module | - | H-Bridge | GND | wire (black) | 15cm | GND |
| H-Bridge | OUT1+ | Motor 1 | - | wire (green) | 20cm | + |
| H-Bridge | OUT1- | Motor 1 | - | wire (blue) | 20cm | - |
| H-Bridge | OUT2+ | Motor 2 | - | wire (green) | 20cm | + |
| H-Bridge | OUT2- | Motor 2 | - | wire (blue) | 20cm | - |

</div>

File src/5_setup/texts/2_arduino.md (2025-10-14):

# Arduino Programming

## HW Required
    
 - Host PC with Arduino Studio IDE installed [see here](https://www.arduino.cc/en/software).
 - Arduino Nano "Every" (Original or clone; Every need for more external interrupts)
 - USB cable to connect Arduino with PC
 - Arduino PCB for Fenrir Project

## Programming

Open the `software/arduino_nano/main/main.ino` file in the Arduino IDE.

<p align=center>
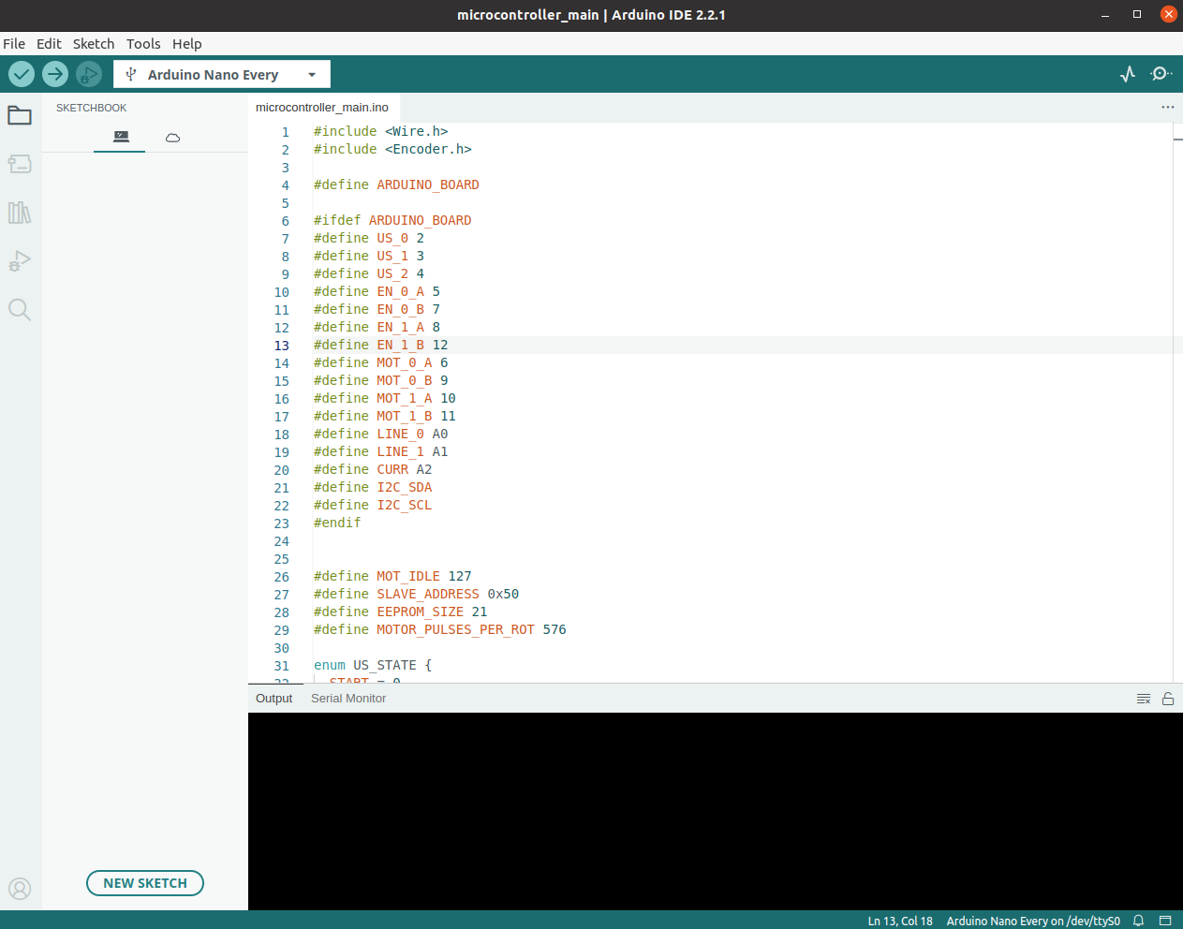
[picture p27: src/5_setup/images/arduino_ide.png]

</p>

Connect the Arduino Every to the 

<p align=center>
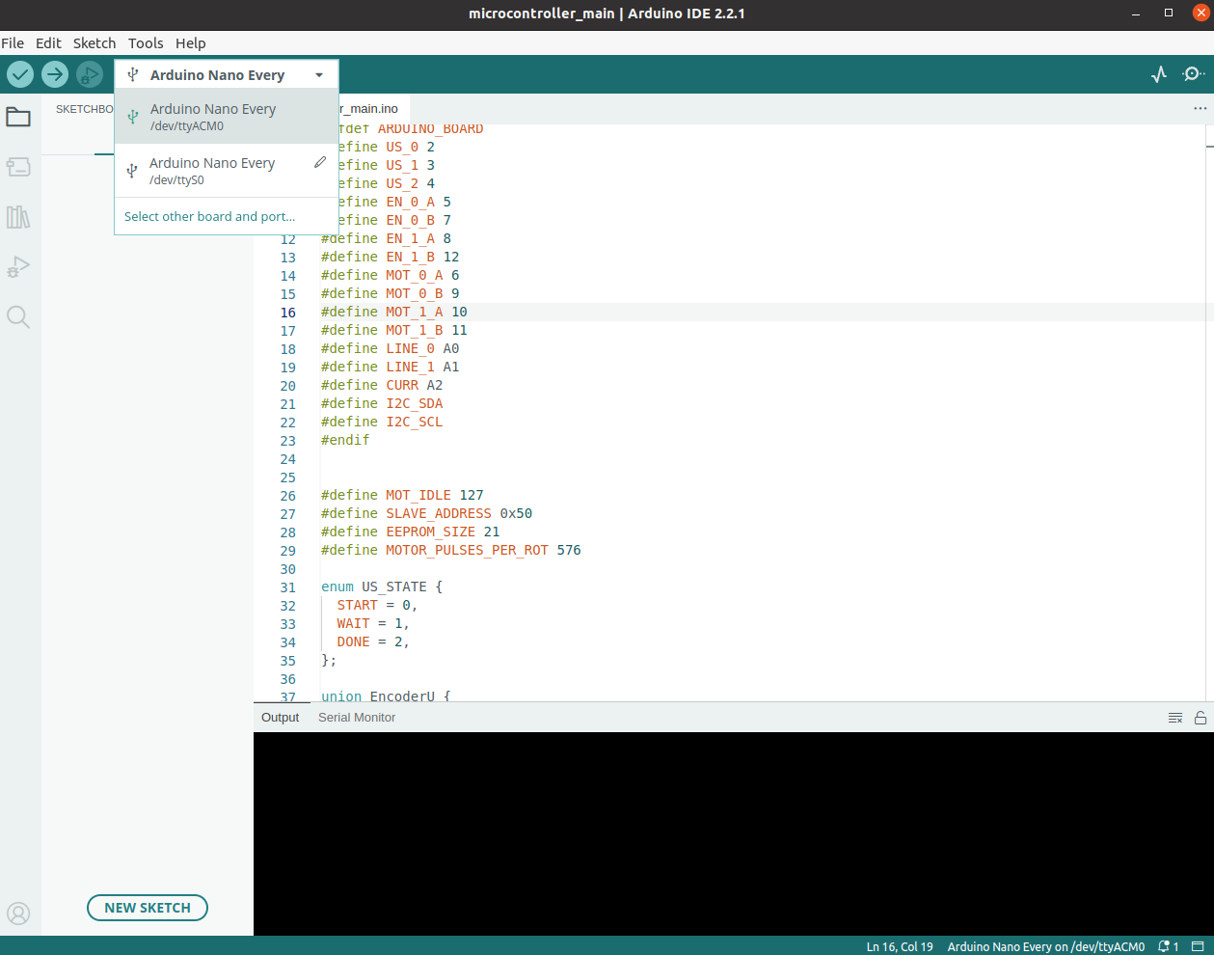
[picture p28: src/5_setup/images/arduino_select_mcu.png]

</p>

Try to build the firmware using the "Verify" button in left top.

<p align=center>
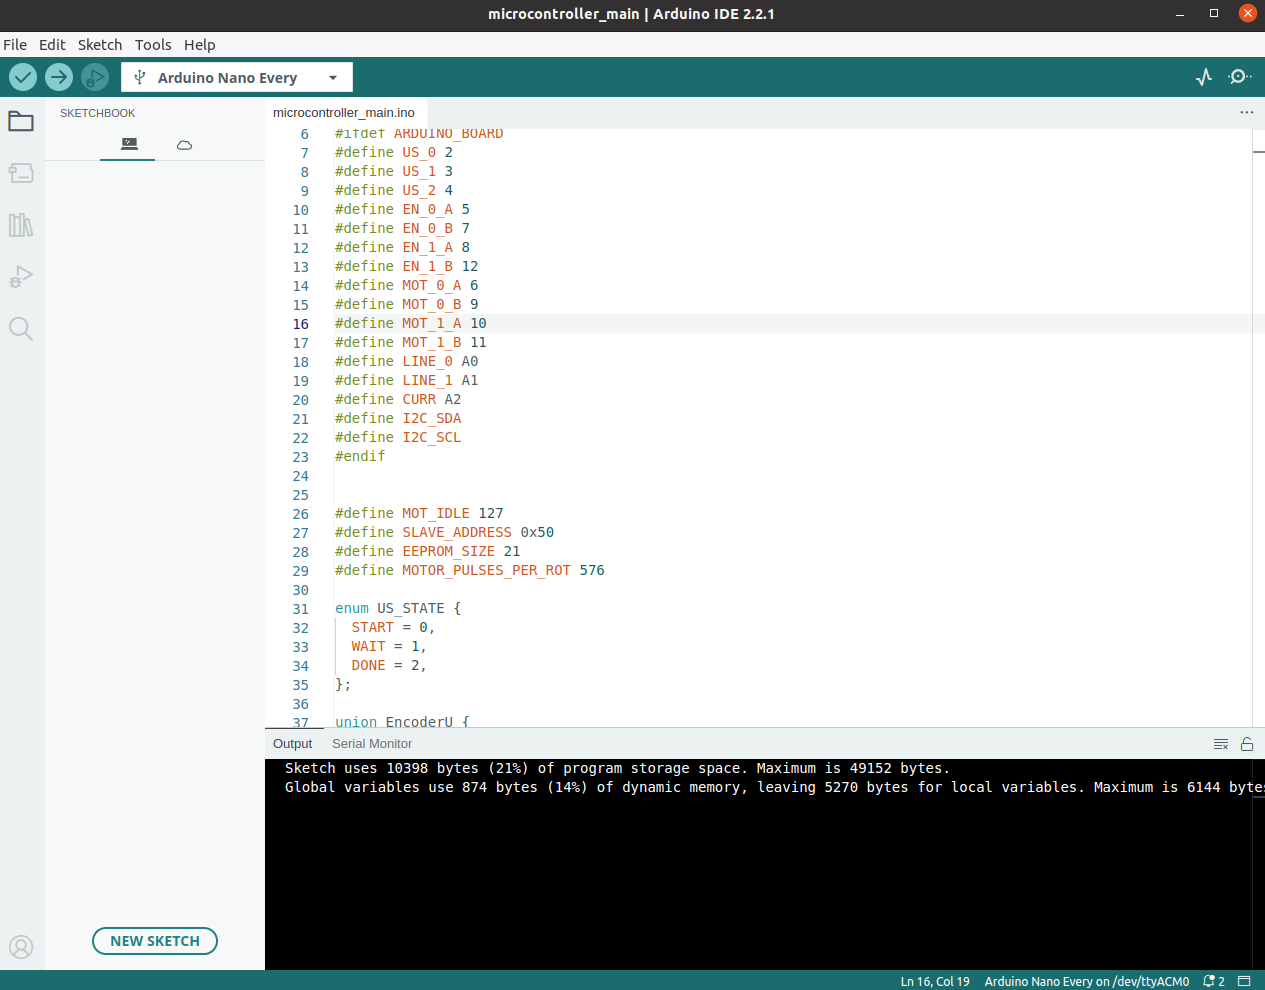
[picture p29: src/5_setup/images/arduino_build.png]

</p>

If build goes ok, try to upload the firmware using the "Upload" button in left top.

<p align=center>
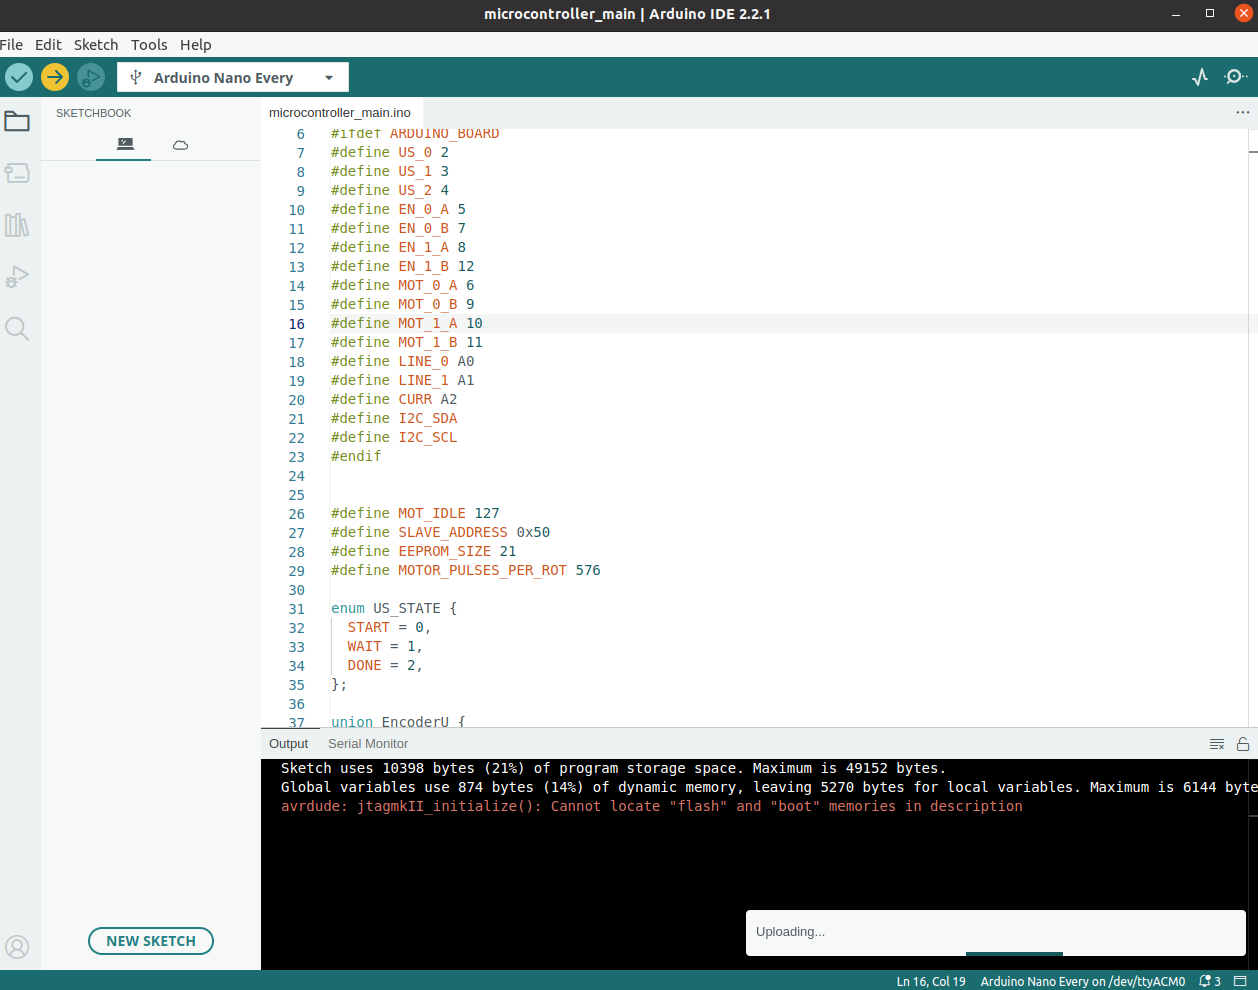
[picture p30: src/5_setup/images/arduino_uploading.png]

</p>

Using the `ctrl+shift+M` open terminal and check if microcontroller communicates.

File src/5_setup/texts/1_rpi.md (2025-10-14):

# RPi Installation

## Required HW

 - Raspberry Pi 4B (8GB RAM recommended)
 - Micro SD Card (minimal 16GB, 64GB recommended)
 - SD Card to USB Adapter

## Installation

Install RPi-Imager on your Linux PC

```
sudo apt install rpi-imager
```

Run RPi-Imager

```
rpi-imager
```

<p align="center">
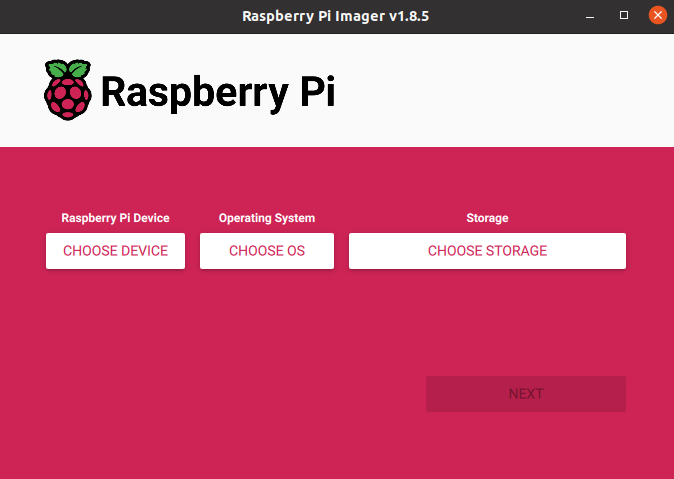
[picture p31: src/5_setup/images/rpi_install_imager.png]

</p>

Select Device (Raspberry Pi 4)

<p align="center">
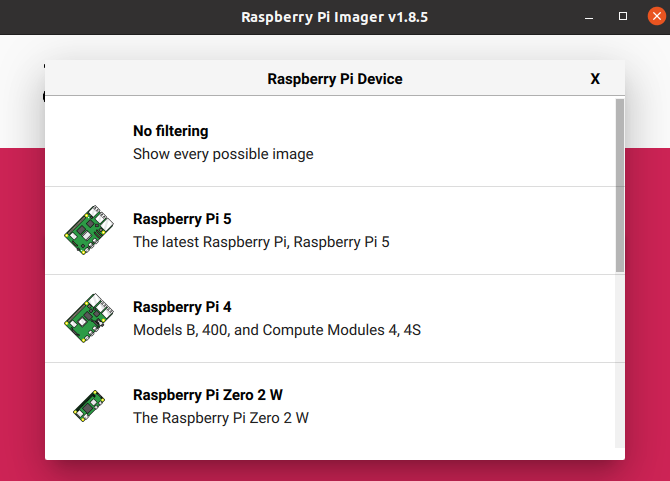
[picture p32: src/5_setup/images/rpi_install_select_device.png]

</p>

Select OS - Others General Purpose OS -> Ubuntu -> Ubuntu Server 22.04.5 LTS (64b)

<p align="center">
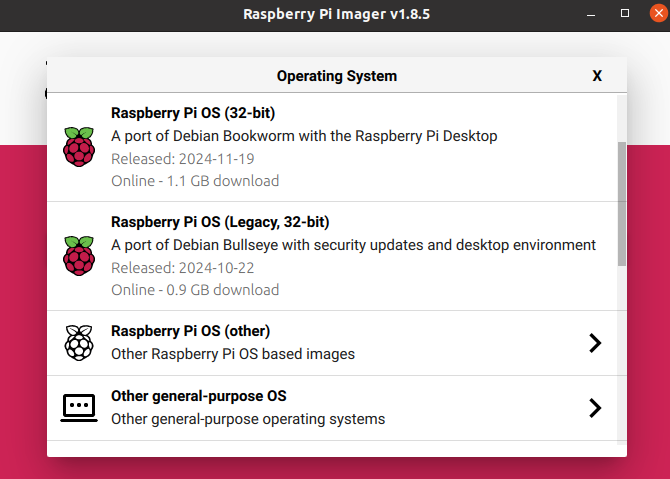
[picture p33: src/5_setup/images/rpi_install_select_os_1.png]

</p>

<p align="center">
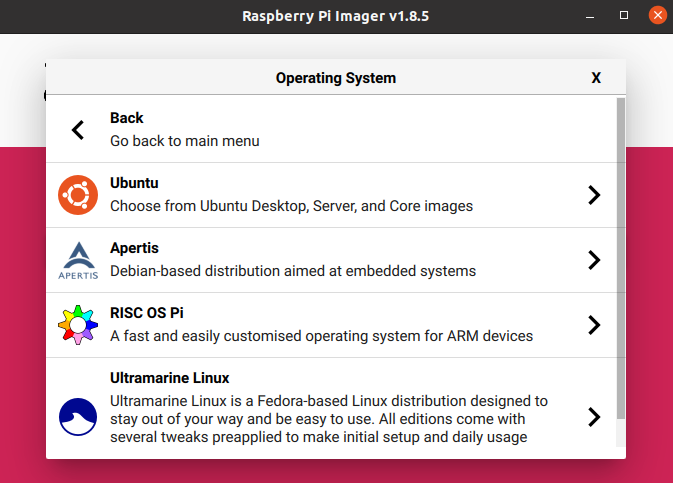
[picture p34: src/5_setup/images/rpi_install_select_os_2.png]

</p>

<p align="center">
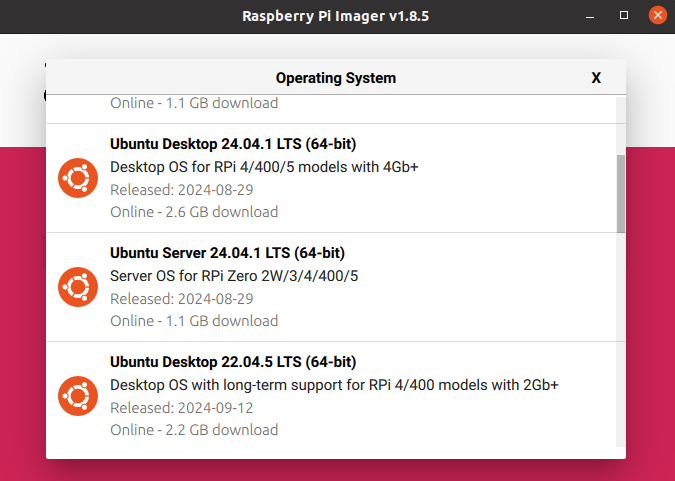
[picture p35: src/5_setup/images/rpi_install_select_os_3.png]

</p>

Select target device (SD Card)

<p align="center">
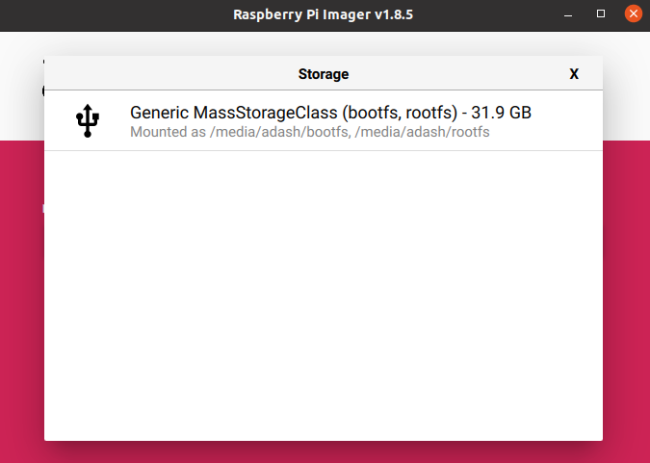
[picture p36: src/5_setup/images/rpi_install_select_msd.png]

</p>

Click Next -> Edit Settings

<p align="center">
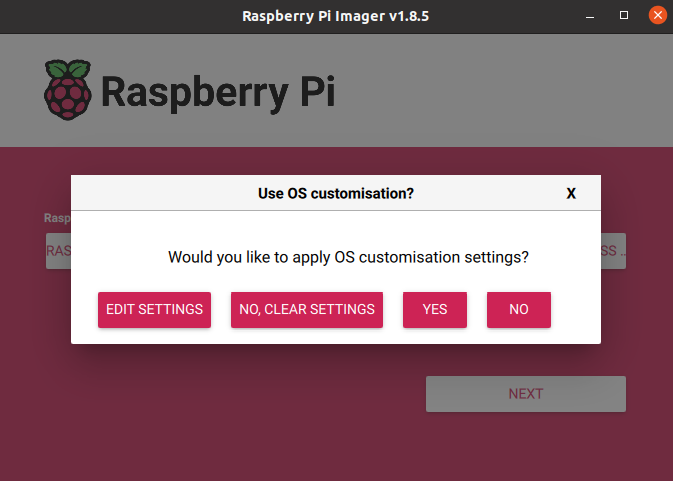
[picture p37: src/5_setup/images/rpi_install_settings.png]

</p>

Setup user, password, WiFi and SSH

<p align="center">
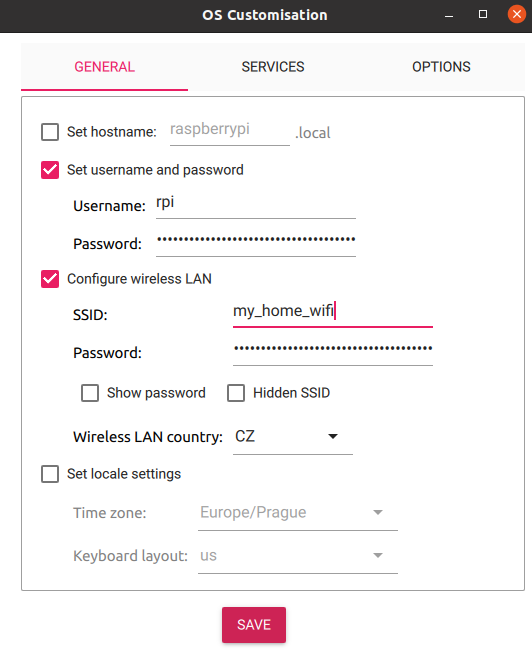
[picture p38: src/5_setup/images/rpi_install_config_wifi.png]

</p>

<p align="center">
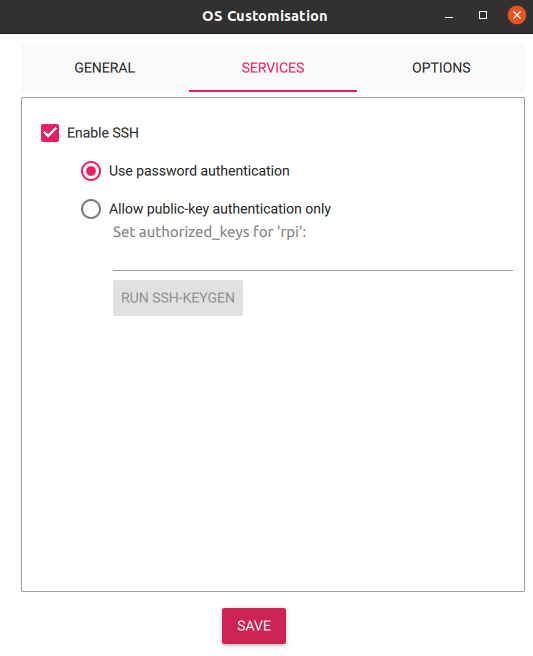
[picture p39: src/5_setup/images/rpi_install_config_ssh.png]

</p>

Confirm and wait until writing is finished.

<p align="center">
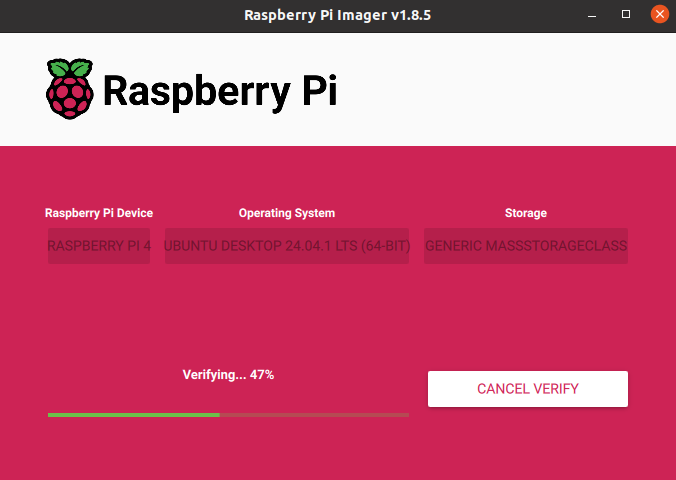
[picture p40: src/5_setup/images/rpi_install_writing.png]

</p>

Now put the SD card into the RPi and power on.

In case of problems, please visit [Official Documentation](https://www.raspberrypi.com/documentation/computers/getting-started.html#install-using-imager) 

## OS Configuration

Connect to the Raspberry Pi

```
ssh <user>@<ip_address>
```

Run first installation script and reboot afterwards. The script may require user input for confirmation on restarting services
Optionaly run script to disable services for faster boot.
```
sudo bash first_start.sh
sudo bash slow_startup.sh #optional
sudo reboot now
```

The script will:
- run system update and upgrade some system packages
- modify the boot firmware config
- create a swapfile (can be removed on systems with more RAM)
- add the user to following groups - `video`, `tty`, `dialout`

The `slow_startup.sh` will disable this services:
- network wait
- snap and related services
- cloud init and related services

After rebooting the system, run the second script.
```
sudo bash installation.sh
```
The script will:
- update system and install necessary packages
- install Python packages
- install ROS 2 and Colcon
- clone `fenrir-project` repository
- build ROS 2 packages
- add services to the system and enable them at startup

If user name is different than "robot", paths in scripts and service files need to be changed, along with the user for one of services.
```
#in repository
fenrir-project/software/raspberry_pi/prp_root.service 
fenrir-project/software/raspberry_pi/prp_user.service 
#or after install
/etc/systemd/system/prp_root.service
/etc/systemd/system/prp_user.service
```
The `ROS_DOMAIN_ID` can be changed in the `*.service` files and optionally (but preferably) in `~/.bashrc`.

## Starting services
Start the necessary services for ROS 2 nodes:
```
sudo systemctl start prp_root.service
sudo systemctl start prp_user.service
```

# Cloning SD card
### Prequisitions: 
- Linux OS
- SD card reader
- A SD card with configured system
- An empty SD card of the same size

Example of how to **clone a SD card** and rename hostname
```bash
# Insert the SD card with the existing system
lsblk # Identify the SD card and its partitions (e.g., /dev/sdc1 and /dev/sdc2)

# Unmout the SD card
sudo umount /dev/sdc*

# Create an image of the SD card with the system
sudo dd if=/dev/sdc of=~/Documents/prp/robot.img bs=4M status=progress  
sudo eject /dev/sdc

# Swap the SD card with an empty one
lsblk # Identify SD card and its partitions (e.g., /dev/sdc1 and /dev/sdc2)
sudo dd if=~/Documents/prp/robot.img of=/dev/sdc bs=4M status=progress # apply image to the SD card
sudo sync

# Mount the SD card's partitions
sudo mkdir /media/jakub/card1
sudo mount /dev/sdc1 /media/jakub/card1
sudo mkdir /media/jakub/card2
sudo mount /dev/sdc2 /media/jakub/card2

# Replace the old hostname for new one
sudo sed -i 's/prp-red/prp-green/g' /media/jakub/card1/user-data /media/jakub/card2/etc/hostname /media/jakub/card2/etc/hosts

# Unmount SD card and remove created folders
sudo umount /media/jakub/card1
sudo umount /media/jakub/card2
sudo rmdir /media/jakub/card1/
sudo rmdir /media/jakub/card2/
```

`ROS_DOMAIN_ID` can be rewritten in files:
```
~/.bashrc
/etc/systemd/system/prp_user.service
/etc/systemd/system/prp_root.service
```

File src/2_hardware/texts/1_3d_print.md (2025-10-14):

# 3D Printed Components

This section lists all parts that need to be 3D-printed and provides recommended printing settings for optimal results.

**Recommended Printing Parameters:**
 - **Printer:** Prusa MK4
 - **Slicer:** PrusaSlicer
 - **Filament:** Prusament PLA or PETG
 - **Infill:** 30%
 - **Layer height:** 0.2 mm
 - **Infill pattern:** Gyroid

### AR Tag Plate - 1x

<p id="ar_tag_plate" align="center">
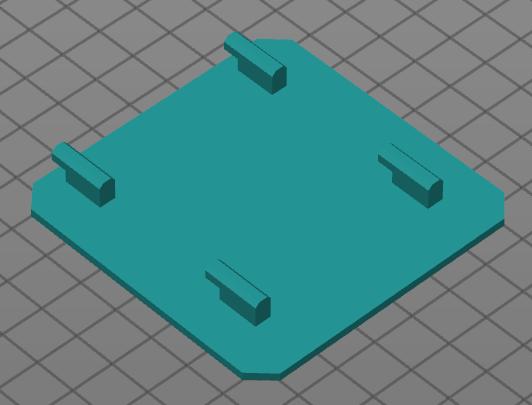
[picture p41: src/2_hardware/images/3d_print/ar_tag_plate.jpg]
AR Tag Plate
  
</p align="center">

### Battery Holder - 2x

<p id="battery_holders" align="center">
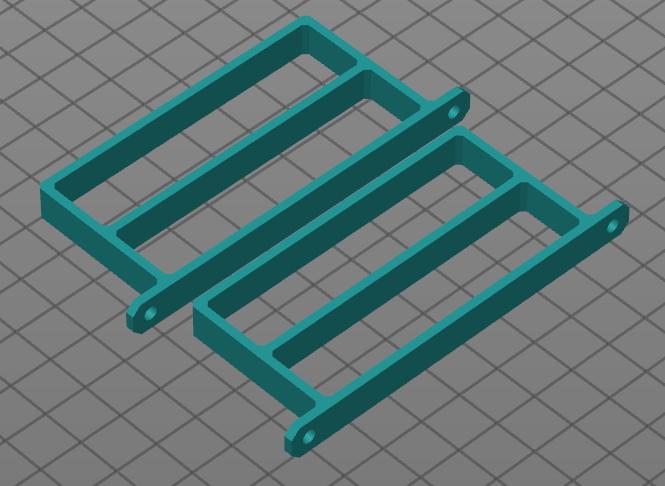
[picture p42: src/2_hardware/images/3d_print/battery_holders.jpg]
Battery Holder
  
</p align="center">

### Camera Mounts - 2x
<p id="camera_mounts" align="center">
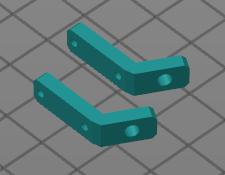
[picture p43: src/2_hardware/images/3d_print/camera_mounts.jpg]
Camera Mount
  
</p align="center">

### Front Leg - 1x

<p id="leg_front_2" align="center">
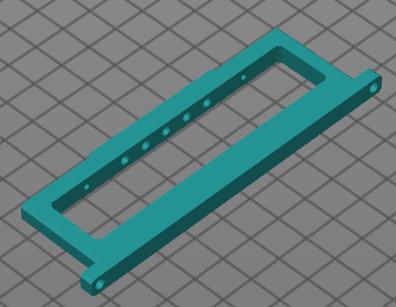
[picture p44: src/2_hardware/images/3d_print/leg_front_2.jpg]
Front Leg
  
</p align="center">

### Rear Leg - 1x

<p id="leg_rear_2" align="center">
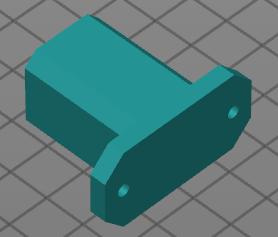
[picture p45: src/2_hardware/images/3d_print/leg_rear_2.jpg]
Leg Rear
  
</p align="center">

### LCD Mount - 1x

<p id="lcd_mount" align="center">
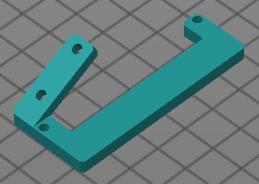
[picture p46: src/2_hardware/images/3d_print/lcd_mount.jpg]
LCD mount
  
</p align="center">

### Plate Bottom - 1x

<p id="plate_bot" align="center">
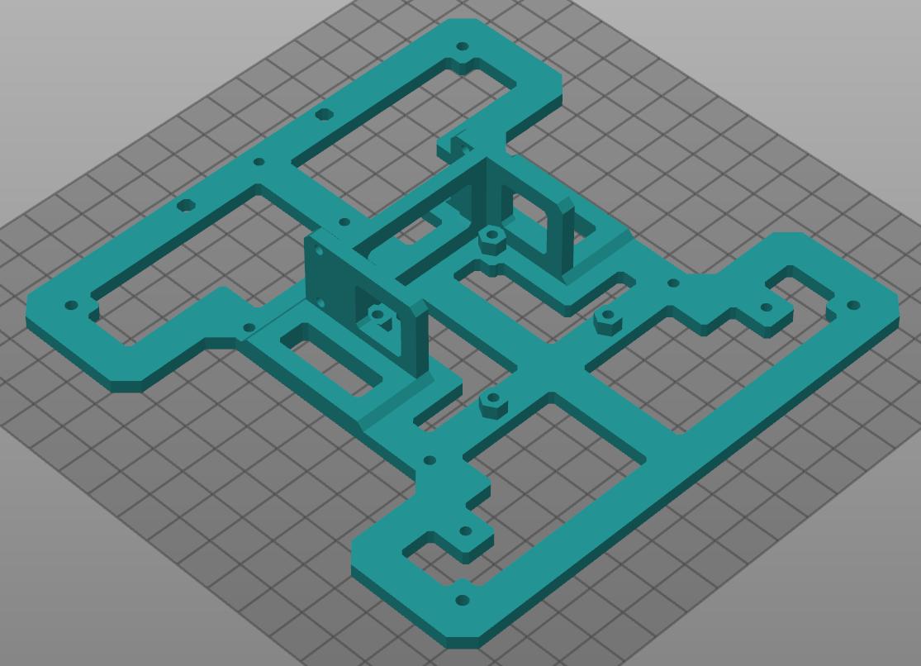
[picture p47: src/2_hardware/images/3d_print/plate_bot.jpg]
Bot Plate
  
</p align="center">

### Plate Middle - 1x

<p id="plate_mid" align="center">
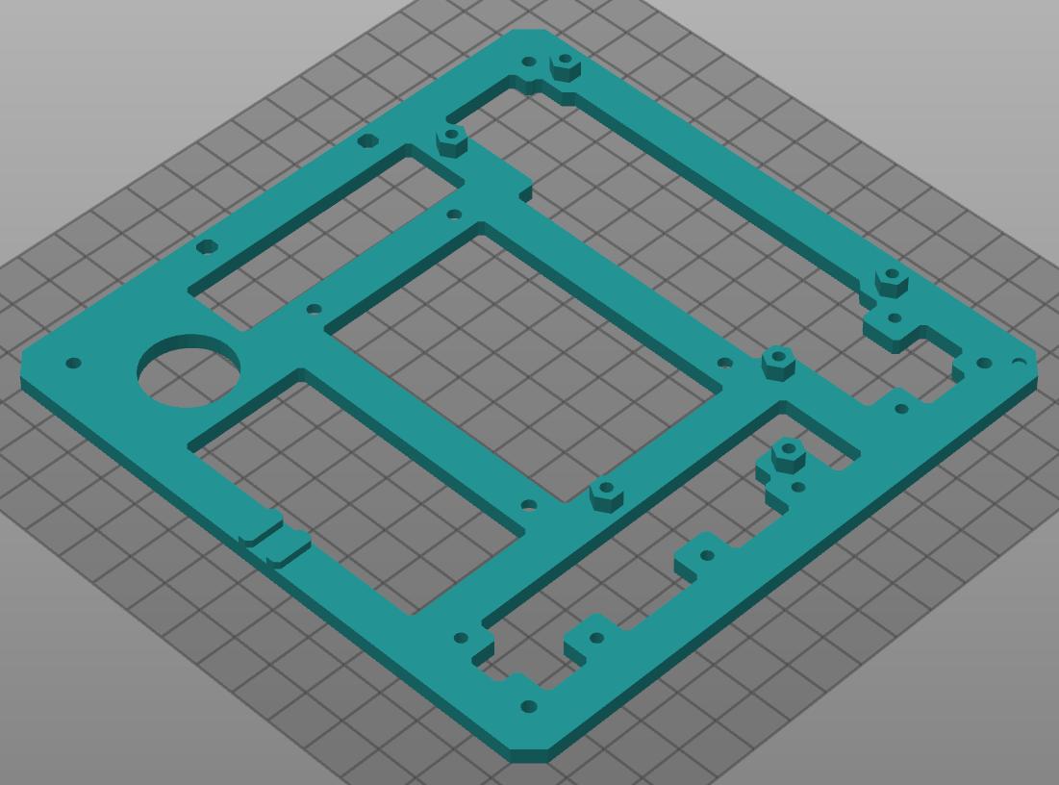
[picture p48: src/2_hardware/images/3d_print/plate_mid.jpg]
Mid Plate
  
</p align="center">

### Plate Top - 1x

<p id="plate_top" align="center">
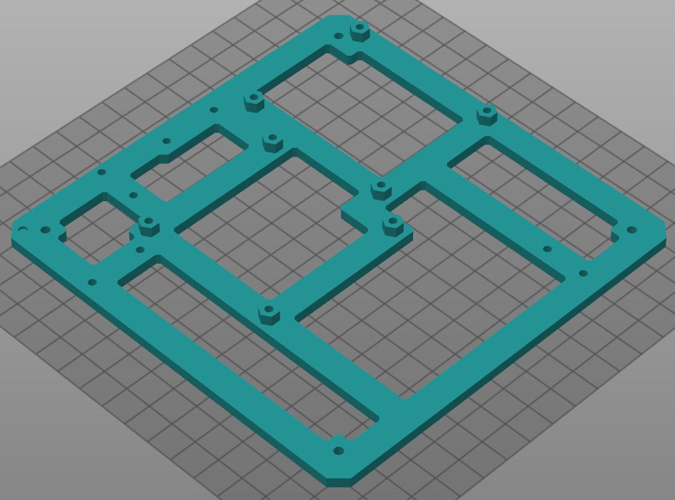
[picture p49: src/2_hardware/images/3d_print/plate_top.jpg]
Top Plate
  
</p align="center">

### SRF05 Mount - 3x

<p id="srf05_mount" align="center">
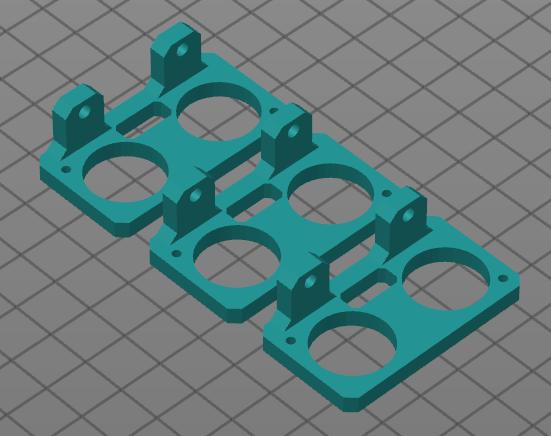
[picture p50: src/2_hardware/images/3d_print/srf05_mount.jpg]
srf mount
  
</p align="center">

### Stand - 1x

<p id="stand" align="center">
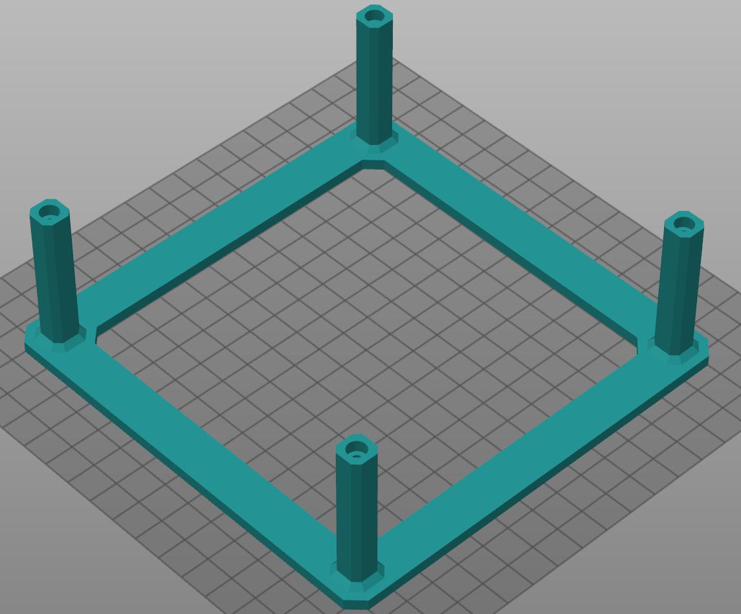
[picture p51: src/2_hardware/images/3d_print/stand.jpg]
Stand
  
</p align="center">

### Wheels - 2x

<p id="wheels" align="center">
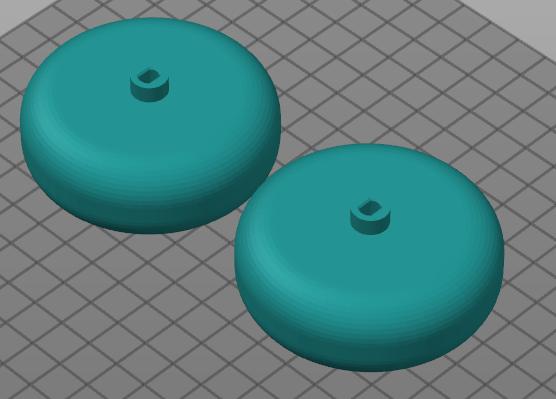
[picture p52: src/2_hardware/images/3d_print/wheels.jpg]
Wheels
  
</p align="center">

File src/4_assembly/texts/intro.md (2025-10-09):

# Robot Assembly

This chapter shows how to assemble the robot.

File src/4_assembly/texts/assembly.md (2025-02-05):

# Robot Assembly

### Step 1 - Battery holder mount

- Bottom part
- Battery holders (2x)
- Screw M3x6 (4x)

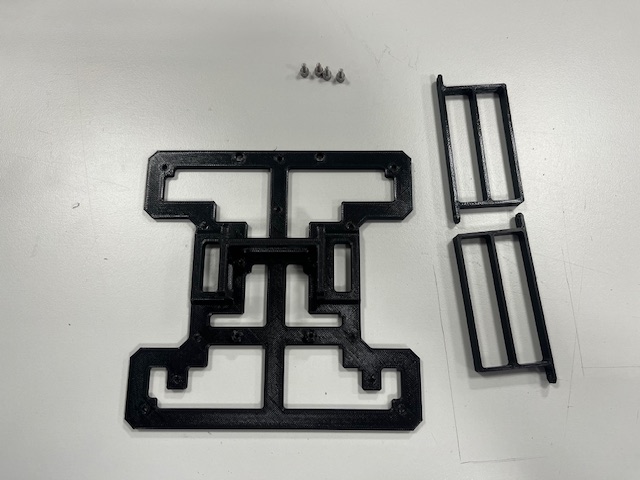
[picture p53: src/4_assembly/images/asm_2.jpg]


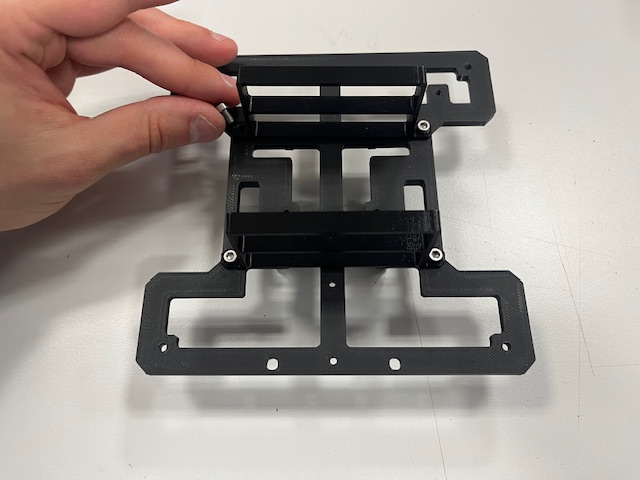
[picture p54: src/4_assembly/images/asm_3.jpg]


### Step 2 - Front Leg mount

- Front leg
- Screw M3x6 (2x)

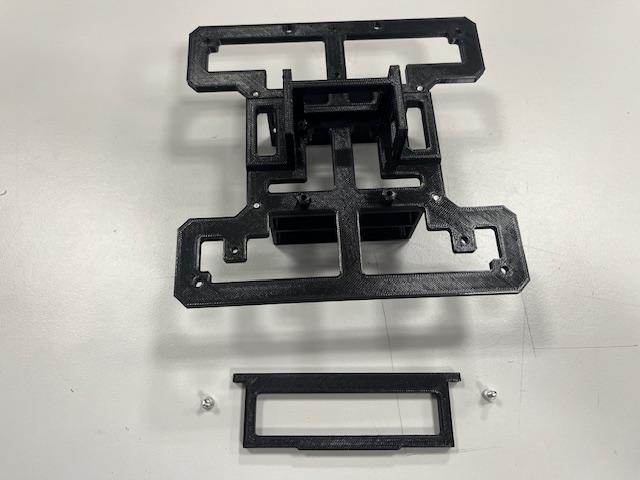
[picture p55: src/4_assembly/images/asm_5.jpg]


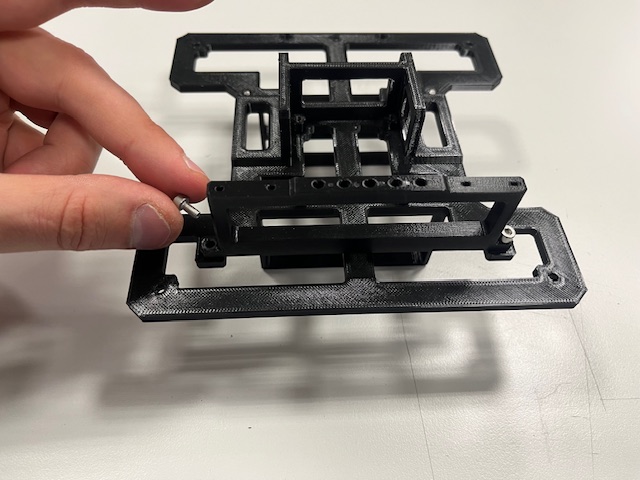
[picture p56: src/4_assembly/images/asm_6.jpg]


### Step 3 - H-Bridge mount

- H-bridge
- screw M3x6 (4x)

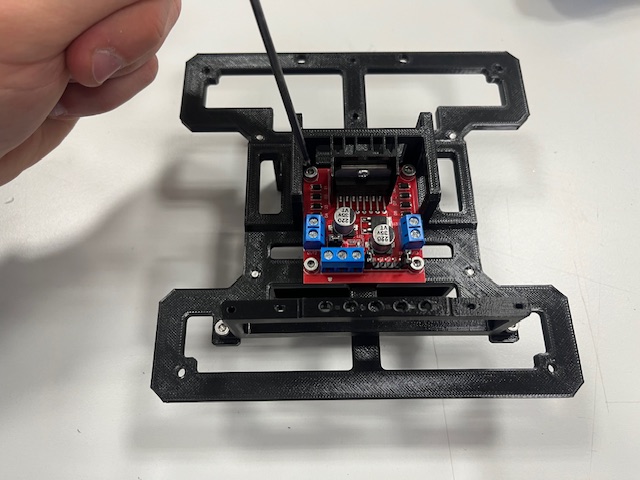
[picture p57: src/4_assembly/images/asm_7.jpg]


### Step 4 - Standoffs

- Standoff (4x)
- Screw M3x6 (4x)

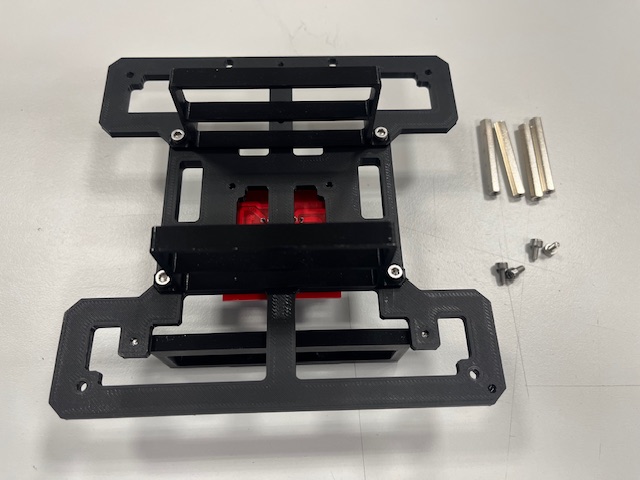
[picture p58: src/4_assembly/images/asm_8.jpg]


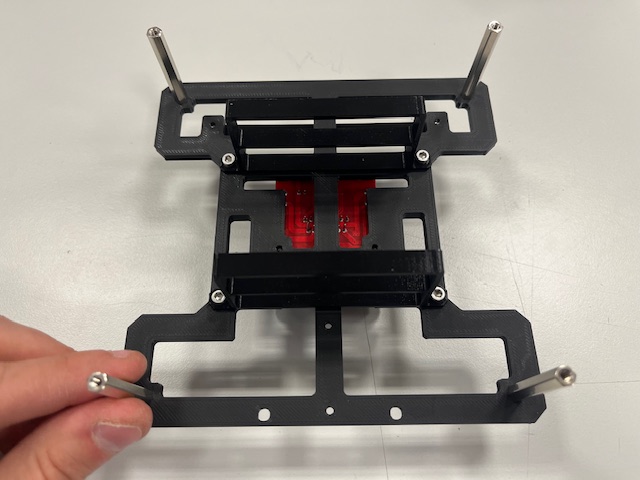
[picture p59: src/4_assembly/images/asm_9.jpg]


### Step 5 - Rear Leg mount

- Rear leg
- Screw M3x6 (2x)

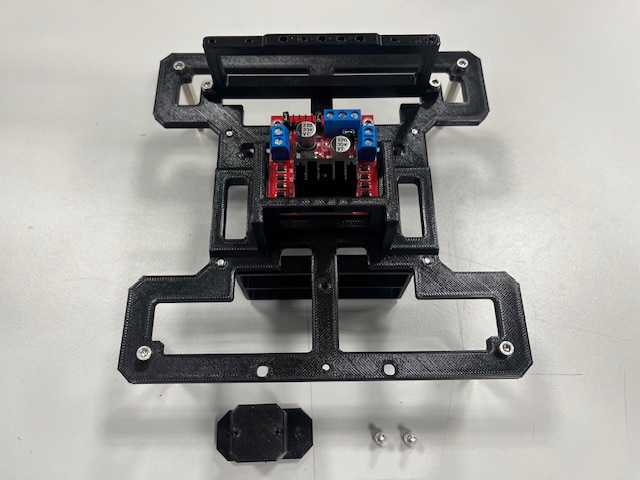
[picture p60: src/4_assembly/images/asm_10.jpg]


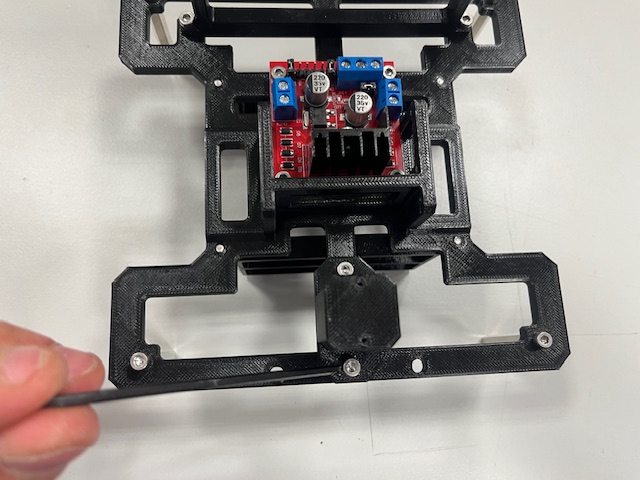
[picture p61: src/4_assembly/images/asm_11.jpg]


### Step 6 - Roller Casters mount

- Roller caster (3x)
- Screw M2x4 (6x)

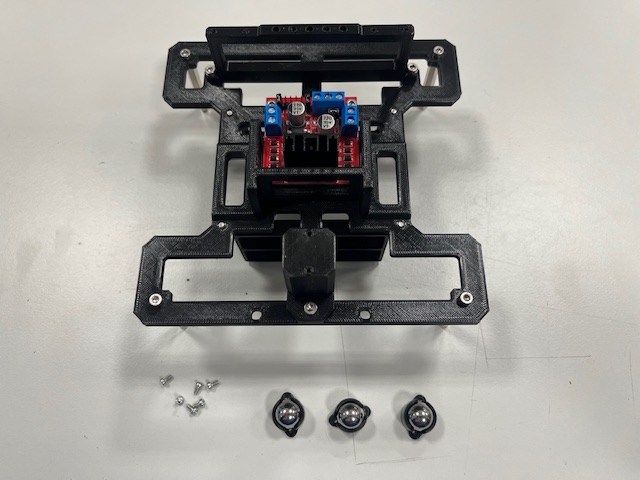
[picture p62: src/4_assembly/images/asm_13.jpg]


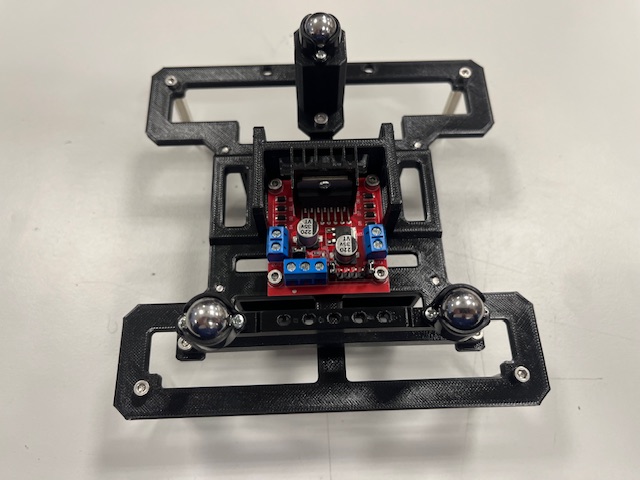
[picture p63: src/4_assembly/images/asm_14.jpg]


### Step 7 - Motors mount

- Motor with 6-wire cable (2x)
- Screw M3x25

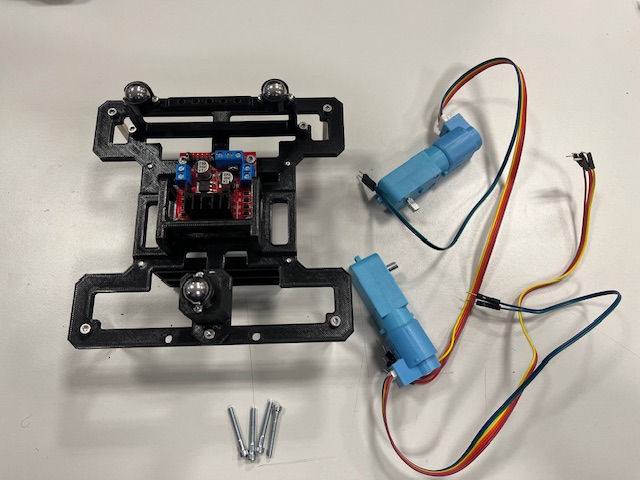
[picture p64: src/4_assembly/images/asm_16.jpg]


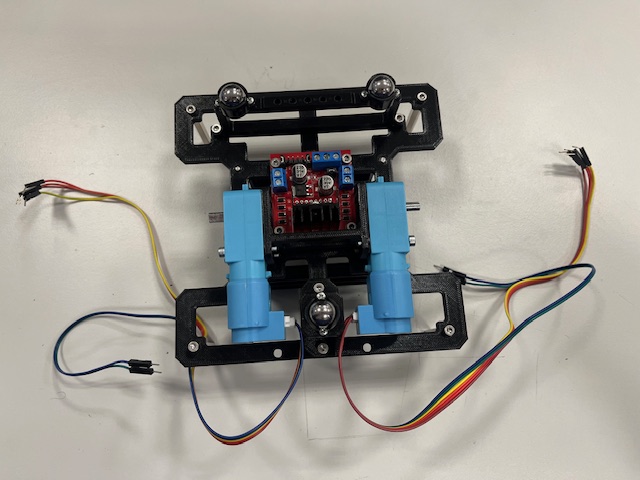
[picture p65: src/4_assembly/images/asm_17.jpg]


### Step 8 - Line Sensors mount

- Line sensor with 3 wires (2x)
  - vcc (red)
  - gnd (black) 
  - signal (blue) 

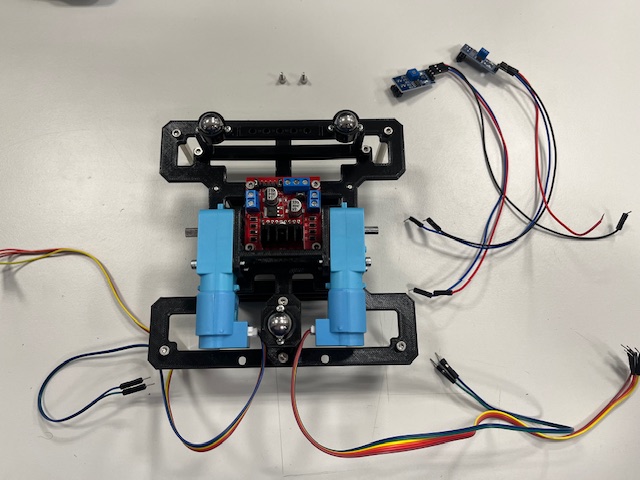
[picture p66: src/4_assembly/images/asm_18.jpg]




### Step 9 - Middle, Switch

- Middle part
- Switch
- USB power delivery module
- Wires (red & black)





### Step 10 - Arduino Board

- Arduino board
- Screw M3x6 (4x)







### Step 11 - LiDAR Mount

- LiDAR with UART to USB converter and 4 screws





### Step 12 - Ultrasound Module assembly

- Ultrasound sensor
- 3 wires 
  - vcc (red)
  - gnd (black)
  - signal (blue)



### Step 13 - US Modules mount

- Ultrasound module (3x)
- Screw M3x6 (6x)





### Step 14 - DC/DC Stepup mount

- DC/DC stepup
- Screw M3x6 (2x)





### Step 15 - Top, LCD

- Top Part
- LCD mount
- LCD
- Wires 
  - vcc (red)
  - gnd (black)
  - sda (green)
  - scl (yellow)



### Step 16 - RPi, Camera

- Raspberry Pi 4
- RPi camera v2
- Camera mount
- 4x screw M2x3





### Step 17 - RPi Module mount

- RPi module





### Step 18 - Sensor Board mount

- Sensor board
  - IMU
  - ADC
  - RTC
  - Magnetometer
  - Barometer







### Step 19 - RPi Hat mount

 - RPi Hat





### Step 20 - Bottom Module wires alignment





### Step 21 - Mid Module wires alignment



### Step 22 - Bot & Mid merge

- Bottom module
- Mid module
- Standoff (4x)





### Step 23 - Connecting Encoders to Arduino Board

- Left motor -> encoder 1
- Right motor -> encoder 2



### Step 24 - Connecting US modules

- Left US -> us_1
- Center US -> us_2
- Right US -> us_3



### Step 25 - Top Module mount

- Top module
- Screw M3x4 (4s)
- Wires (RPi power -> Arduino Board) 
  - 5V (red)
  - gnd (black)





### Step 26 - Connecting I2C RPi <-> Aruino Board

- Wires
  - sda (green)
  - scl (yellow)



### Step 27 - Wiring Arduino Board -> H-Bridge
- Left motor
  - M1A -> N1 (yellow)
  - M1B -> N2 (green)
- Right motor
  - M2A -> N3 (yellow)
  - M2B -> N4 (green)



### Step 28 - Connecting RPi Power to Sensor Board
 - vcc 5V (red)
 - gnd (black)
 - sda (gree)
 - scl (yellow)



### Step 29 - Power Up





### Step 30 - Wheels

- Wheel (2x)



### Final



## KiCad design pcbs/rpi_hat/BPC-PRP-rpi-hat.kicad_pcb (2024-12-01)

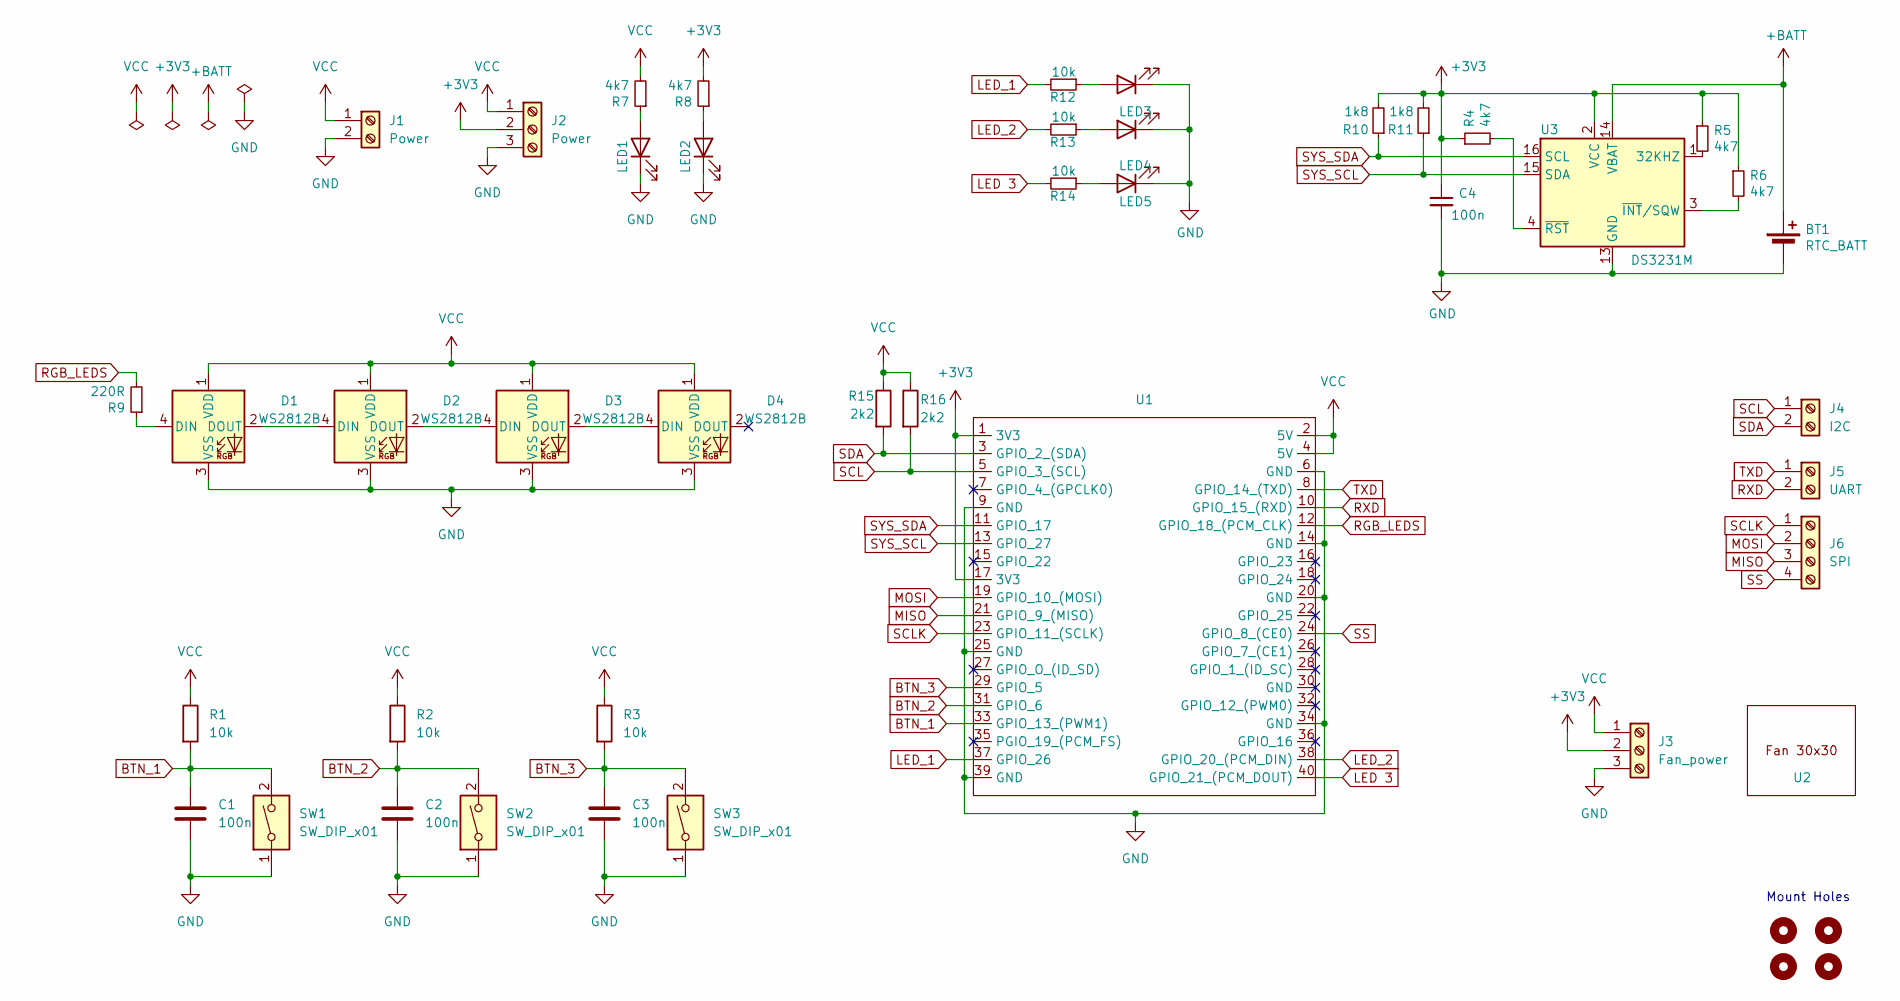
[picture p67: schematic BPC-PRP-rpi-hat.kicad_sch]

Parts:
BT1: RTC_BATT; BatteryHolder_Keystone_3000_1x12mm
C1, C2, C3, C4: 100n; C_1206_3216Metric
D1, D2, D3, D4: WS2812B; LED_WS2812B_PLCC4_5.0x5.0mm_P3.2mm
H1, H2, H3, H4: MountingHole; MountingHole_3.2mm_M3
J1: Power; TerminalBlock_RND_205-00001_1x02_P5.00mm_Horizontal
J2: Power; TerminalBlock_TE_282834-3_1x03_P2.54mm_Horizontal
J3: Fan_power; TerminalBlock_TE_282834-3_1x03_P2.54mm_Horizontal
J4: I2C; TerminalBlock_TE_282834-2_1x02_P2.54mm_Horizontal
J5: UART; TerminalBlock_TE_282834-2_1x02_P2.54mm_Horizontal
J6: SPI; TerminalBlock_TE_282834-4_1x04_P2.54mm_Horizontal
LED1, LED2, LED3, LED4, LED5: LED_1206_3216Metric
R1, R2, R3, R12, R13, R14: 10k; R_1206_3216Metric
R4, R5, R6, R7, R8: 4k7; R_1206_3216Metric
R9: 220R; R_1206_3216Metric
R10, R11: 1k8; R_1206_3216Metric
R15, R16: 2k2; R_1206_3216Metric
SW1, SW2, SW3: SW_DIP_x01; SW_PUSH_6mm_H5mm
U1: PinSocket_2x20_P2.54mm_Vertical
U2: FAN_30
U3: DS3231M; SOIC-16W_7.5x10.3mm_P1.27mm

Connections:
+3V3: C4.1, J2.2, J3.2, R4.1, R5.1, R6.1, R8.2, R10.2, R11.2, U1.1 (3V3), U1.17 (3V3), U3.2 (VCC)
+BATT: BT1.1 (+), U3.14 (VBAT)
BTN_1: C1.1, R1.2, SW1.2, U1.33 (GPIO_13_(PWM1))
BTN_2: C2.1, R2.2, SW2.2, U1.31 (GPIO_6)
BTN_3: C3.1, R3.2, SW3.2, U1.29 (GPIO_5)
GND: BT1.2 (-), C1.2, C2.2, C3.2, C4.2, D1.3 (VSS), D2.3 (VSS), D3.3 (VSS), D4.3 (VSS), J1.2, J2.3, J3.3, LED1.1 (K), LED2.1 (K), LED3.1 (K), LED4.1 (K), LED5.1 (K), SW1.1, SW2.1, SW3.1, U1.6 (GND), U1.9 (GND), U1.14 (GND), U1.20 (GND), U1.25 (GND), U1.34 (GND), U1.39 (GND), U3.5 (GND), U3.6 (GND), U3.7 (GND), U3.8 (GND), U3.9 (GND), U3.10 (GND), U3.11 (GND), U3.12 (GND), U3.13 (GND)
LED 3: R14.2, U1.40 (GPIO_21_(PCM_DOUT))
LED_1: R12.2, U1.37 (GPIO_26)
LED_2: R13.2, U1.38 (GPIO_20_(PCM_DIN))
MISO: J6.3, U1.21 (GPIO_9_(MISO))
MOSI: J6.2, U1.19 (GPIO_10_(MOSI))
unnamed: D1.4 (DIN), R9.1
unnamed: D1.2 (DOUT), D2.4 (DIN)
unnamed: D2.2 (DOUT), D3.4 (DIN)
unnamed: D3.2 (DOUT), D4.4 (DIN)
unnamed: LED1.2 (A), R7.1
unnamed: LED2.2 (A), R8.1
unnamed: LED3.2 (A), R12.1
unnamed: LED4.2 (A), R13.1
unnamed: LED5.2 (A), R14.1
unnamed: R5.2, U3.1 (32KHZ)
unnamed: R6.2, U3.3 (~INT/SQW)
unnamed: R4.2, U3.4 (~RST)
RGB_LEDS: R9.2, U1.12 (GPIO_18_(PCM_CLK))
RXD: J5.2, U1.10 (GPIO_15_(RXD))
SCL: J4.1, R16.2, U1.5 (GPIO_3_(SCL))
SCLK: J6.1, U1.23 (GPIO_11_(SCLK))
SDA: J4.2, R15.2, U1.3 (GPIO_2_(SDA))
SS: J6.4, U1.24 (GPIO_8_(CE0))
SYS_SCL: R11.1, U1.13 (GPIO_27), U3.15 (SDA)
SYS_SDA: R10.1, U1.11 (GPIO_17), U3.16 (SCL)
TXD: J5.1, U1.8 (GPIO_14_(TXD))
VCC: D1.1 (VDD), D2.1 (VDD), D3.1 (VDD), D4.1 (VDD), J1.1, J2.1, J3.1, R1.1, R2.1, R3.1, R7.2, R15.1, R16.1, U1.2 (5V), U1.4 (5V)

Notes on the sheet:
Mount Holes

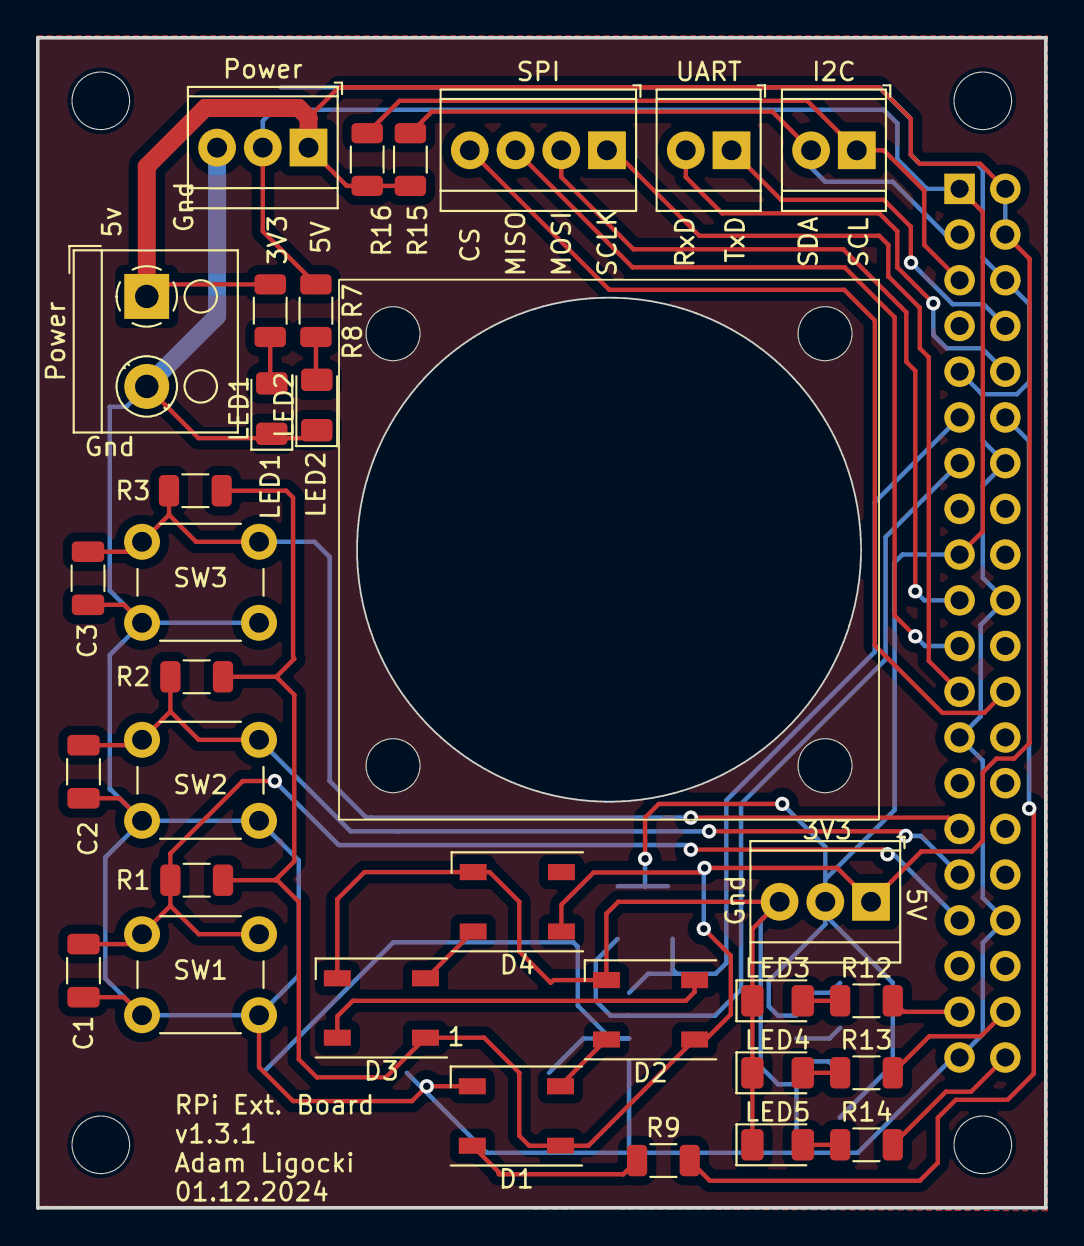
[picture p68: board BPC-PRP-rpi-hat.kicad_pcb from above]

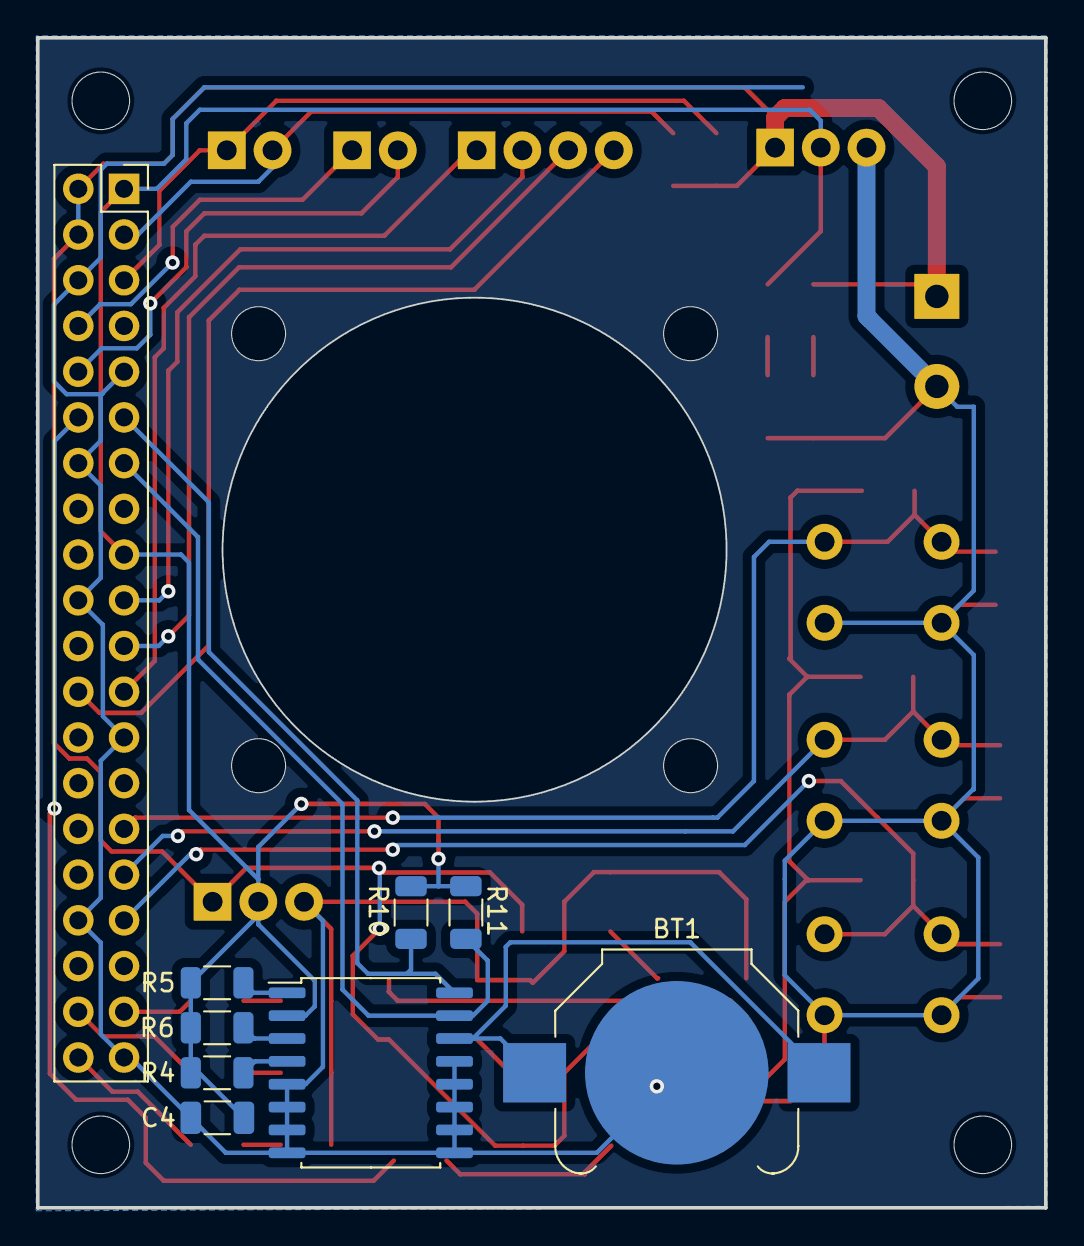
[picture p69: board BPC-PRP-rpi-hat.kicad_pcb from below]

Board: 2 copper layers, 56.0 x 65.0 mm, 46 parts (9 on the bottom side), 33 nets.

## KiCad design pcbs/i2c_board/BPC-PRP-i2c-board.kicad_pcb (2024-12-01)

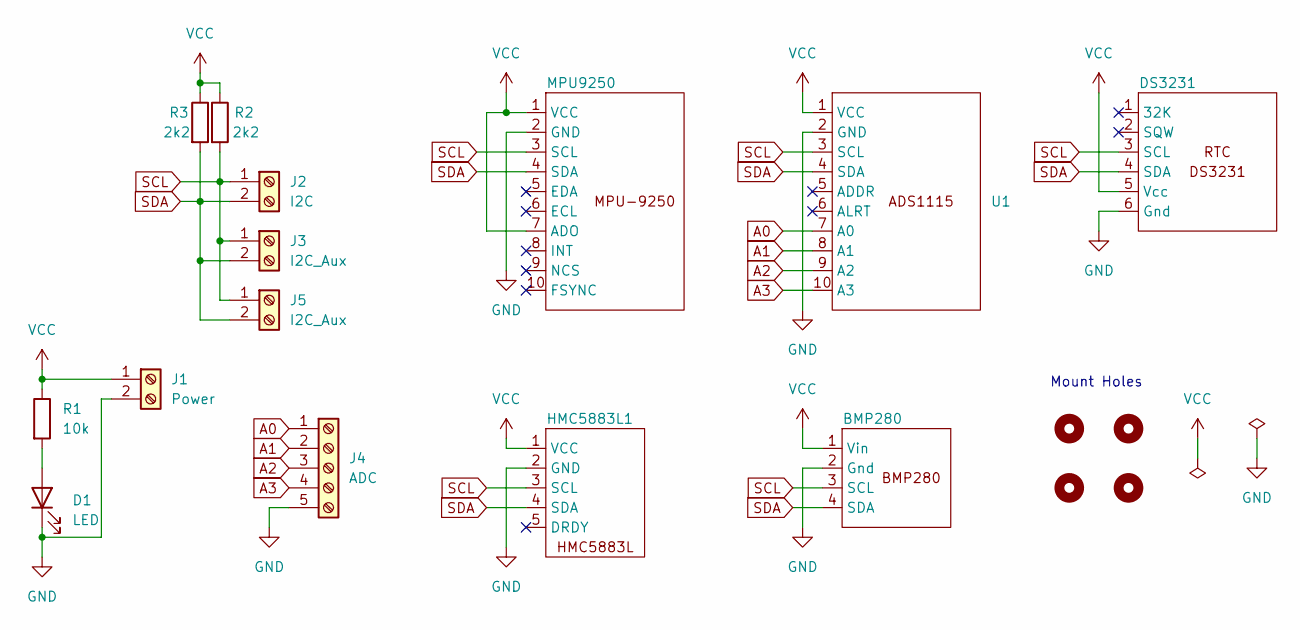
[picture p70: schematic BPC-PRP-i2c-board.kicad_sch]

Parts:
BMP280: bmp280
D1: LED; LED_1206_3216Metric
DS3231: rtc_ds3231
H1, H2, H3, H4: MountingHole; MountingHole_3.2mm_M3
HMC5883L1: HMC5883L
J1: Power; TerminalBlock_TE_282834-2_1x02_P2.54mm_Horizontal
J2: I2C; TerminalBlock_TE_282834-2_1x02_P2.54mm_Horizontal
J3, J5: I2C_Aux; TerminalBlock_TE_282834-2_1x02_P2.54mm_Horizontal
J4: ADC; TerminalBlock_TE_282834-5_1x05_P2.54mm_Horizontal
MPU9250: MPU-9250
R1: 10k; R_1206_3216Metric
R2, R3: 2k2; R_1206_3216Metric
U1: ADS1115

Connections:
A0: J4.1, U1.7 (A0)
A1: J4.2, U1.8 (A1)
A2: J4.3, U1.9 (A2)
A3: J4.4, U1.10 (A3)
GND: BMP280.2 (Gnd), D1.1 (K), DS3231.6 (Gnd), HMC5883L1.2 (GND), J1.2, J4.5, MPU9250.2 (GND), U1.2 (GND)
unnamed: D1.2 (A), R1.2
SCL: BMP280.3 (SCL), DS3231.3 (SCL), HMC5883L1.3 (SCL), J2.1, J3.1, J5.1, MPU9250.3 (SCL), R2.2, U1.3 (SCL)
SDA: BMP280.4 (SDA), DS3231.4 (SDA), HMC5883L1.4 (SDA), J2.2, J3.2, J5.2, MPU9250.4 (SDA), R3.2, U1.4 (SDA)
VCC: BMP280.1 (Vin), DS3231.5 (Vcc), HMC5883L1.1 (VCC), J1.1, MPU9250.1 (VCC), MPU9250.7 (ADO), R1.1, R2.1, R3.1, U1.1 (VCC)

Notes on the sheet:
Mount Holes

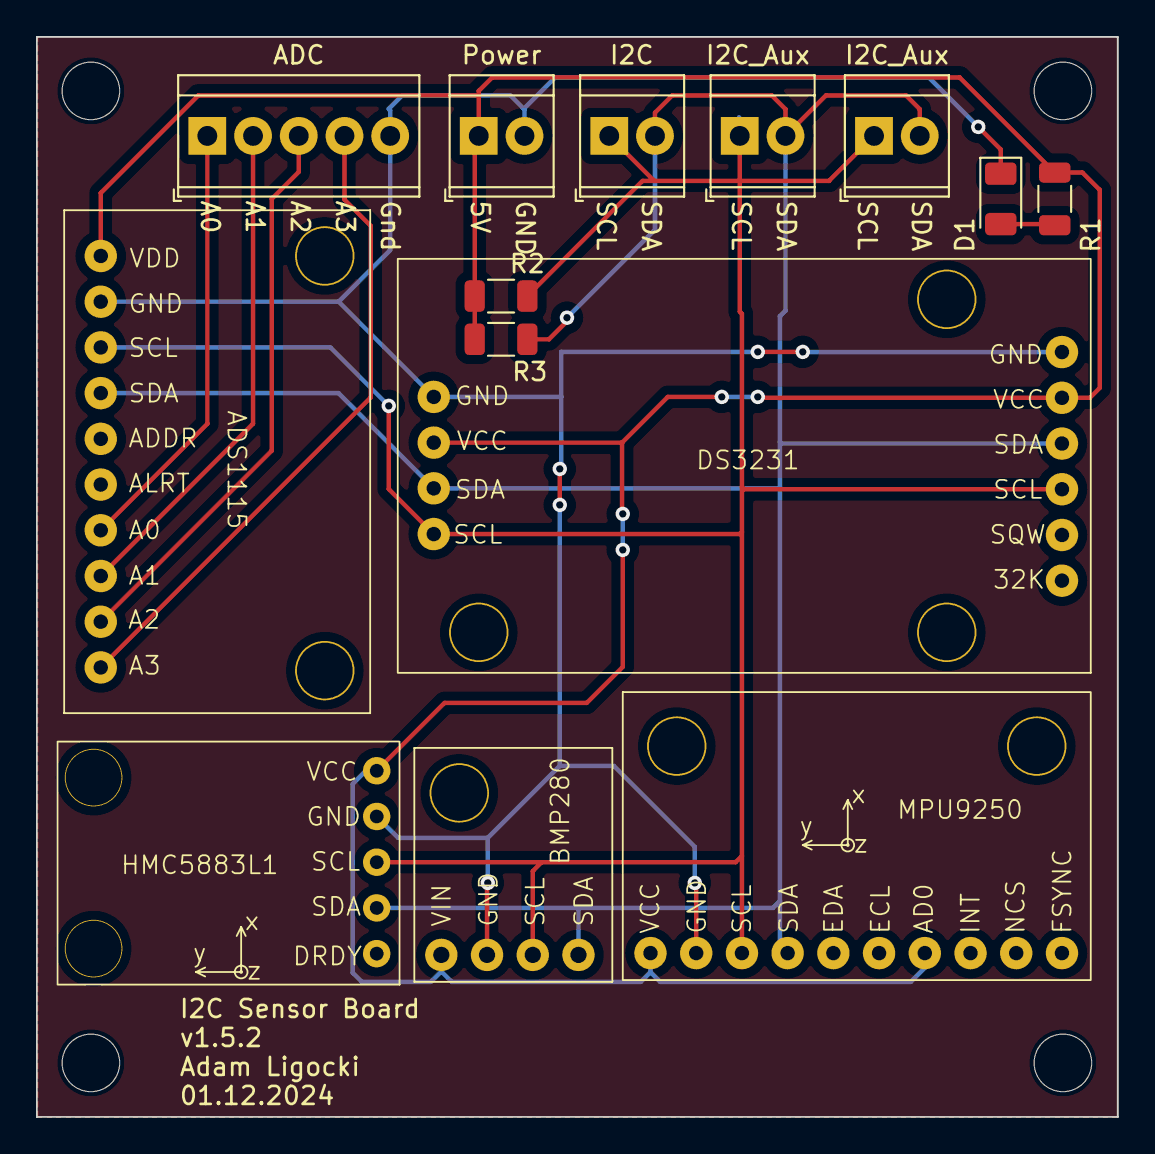
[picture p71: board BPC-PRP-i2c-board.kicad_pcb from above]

Board: 2 copper layers, 60.0 x 60.0 mm, 18 parts (0 on the bottom side), 9 nets.

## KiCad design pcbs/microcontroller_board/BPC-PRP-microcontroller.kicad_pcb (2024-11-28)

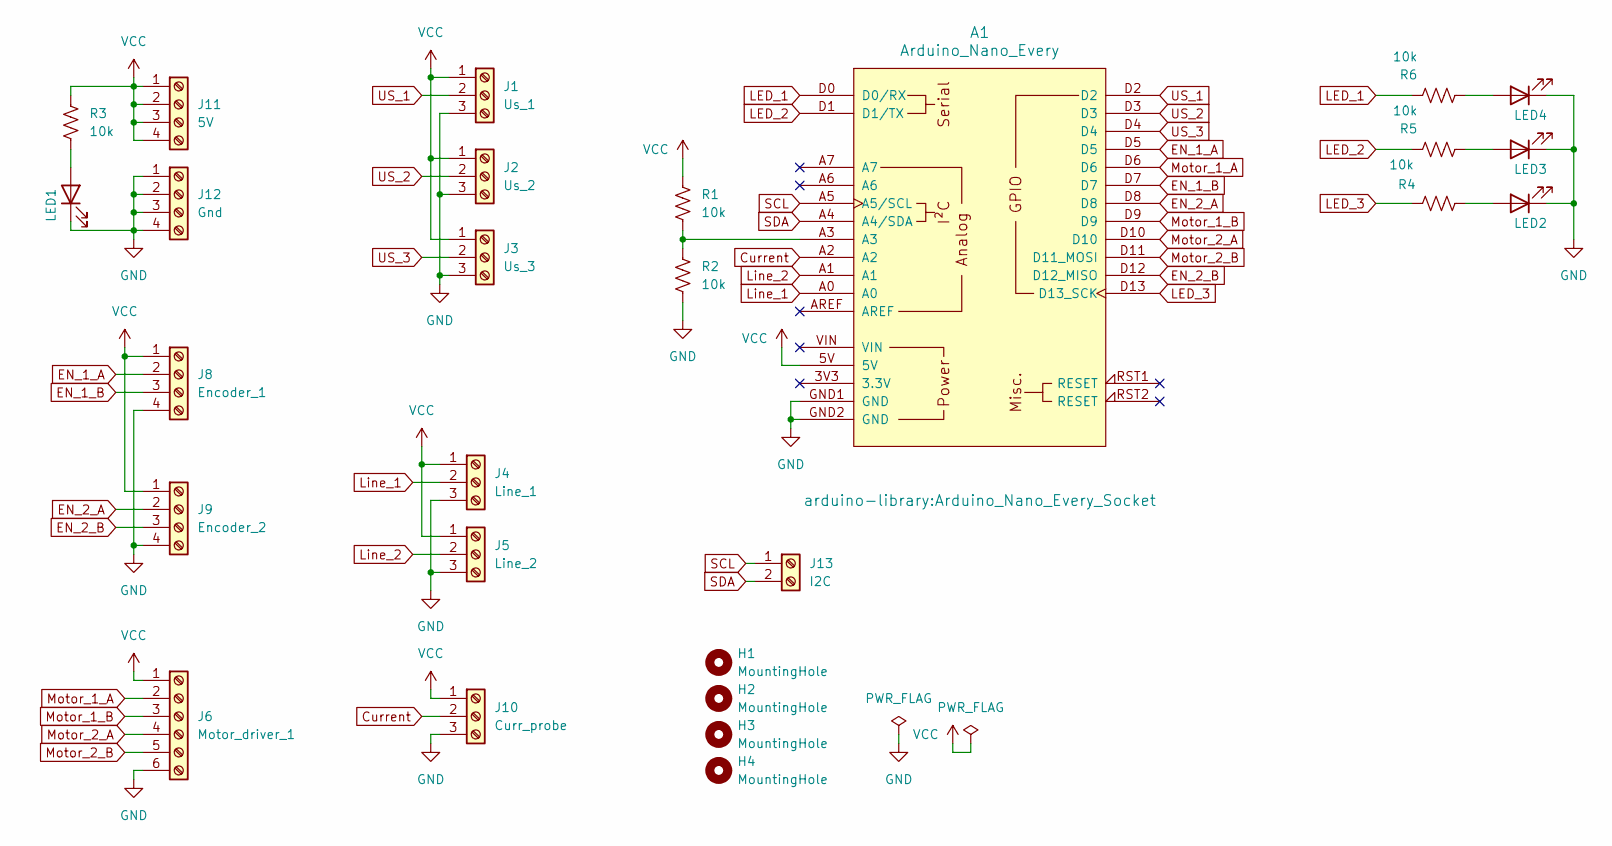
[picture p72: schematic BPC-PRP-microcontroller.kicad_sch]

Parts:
A1: Arduino_Nano_Every; Arduino_Nano_Every_Socket
H1, H2, H3, H4: MountingHole; MountingHole_3.2mm_M3
J1: Us_1; TerminalBlock_TE_282834-3_1x03_P2.54mm_Horizontal
J2: Us_2; TerminalBlock_TE_282834-3_1x03_P2.54mm_Horizontal
J3: Us_3; TerminalBlock_TE_282834-3_1x03_P2.54mm_Horizontal
J4: Line_1; TerminalBlock_TE_282834-3_1x03_P2.54mm_Horizontal
J5: Line_2; TerminalBlock_TE_282834-3_1x03_P2.54mm_Horizontal
J6: Motor_driver_1; TerminalBlock_TE_282834-6_1x06_P2.54mm_Horizontal
J8: Encoder_1; TerminalBlock_TE_282834-4_1x04_P2.54mm_Horizontal
J9: Encoder_2; TerminalBlock_TE_282834-4_1x04_P2.54mm_Horizontal
J10: Curr_probe; TerminalBlock_TE_282834-3_1x03_P2.54mm_Horizontal
J11: 5V; TerminalBlock_TE_282834-4_1x04_P2.54mm_Horizontal
J12: Gnd; TerminalBlock_TE_282834-4_1x04_P2.54mm_Horizontal
J13: I2C; TerminalBlock_TE_282834-2_1x02_P2.54mm_Horizontal
LED1, LED2, LED3, LED4: LED_1206_3216Metric
R1, R2, R3, R4, R5, R6: 10k; R_1206_3216Metric

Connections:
Current: A1.A2, J10.2
EN_1_A: A1.D5, J8.2
EN_1_B: A1.D7, J8.3
EN_2_A: A1.D8, J9.2
EN_2_B: A1.D12 (D12_MISO), J9.3
GND: A1.GND1 (GND), A1.GND2 (GND), J1.3, J2.3, J3.3, J4.3, J5.3, J6.6, J8.4, J9.4, J10.3, J12.1, J12.2, J12.3, J12.4, LED1.1 (K), LED2.1 (K), LED3.1 (K), LED4.1 (K), R2.2
LED_1: A1.D0 (D0/RX), R6.1
LED_2: A1.D1 (D1/TX), R5.1
LED_3: A1.D13 (D13_SCK), R4.1
Line_1: A1.A0, J4.2
Line_2: A1.A1, J5.2
Motor_1_A: A1.D6, J6.2
Motor_1_B: A1.D9, J6.3
Motor_2_A: A1.D10, J6.4
Motor_2_B: A1.D11 (D11_MOSI), J6.5
unnamed: A1.A3, R1.2, R2.1
unnamed: LED1.2 (A), R3.2
unnamed: LED2.2 (A), R4.2
unnamed: LED3.2 (A), R5.2
unnamed: LED4.2 (A), R6.2
SCL: A1.A5 (A5/SCL), J13.1
SDA: A1.A4 (A4/SDA), J13.2
US_1: A1.D2, J1.2
US_2: A1.D3, J2.2
US_3: A1.D4, J3.2
VCC: A1.5V, J1.1, J2.1, J3.1, J4.1, J5.1, J6.1, J8.1, J9.1, J10.1, J11.1, J11.2, J11.3, J11.4, R1.1, R3.1

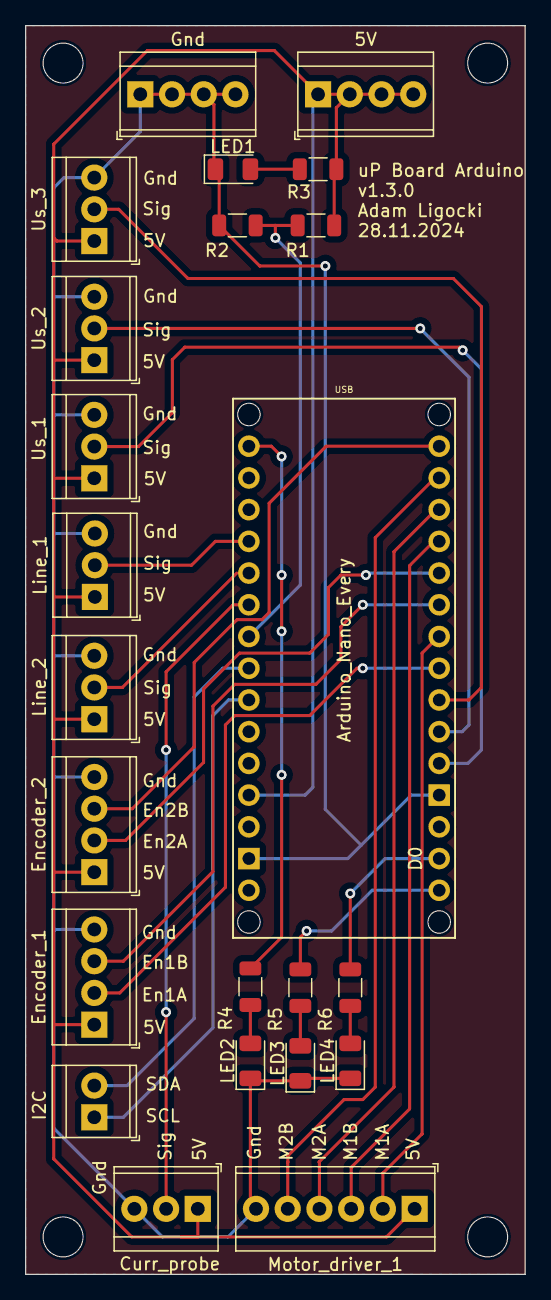
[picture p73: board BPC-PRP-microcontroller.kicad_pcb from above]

Board: 2 copper layers, 40.0 x 100.0 mm, 27 parts (0 on the bottom side), 26 nets.

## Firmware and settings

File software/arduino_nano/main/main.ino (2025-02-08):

#include <Wire.h>
#include <Encoder.h>

#define ARDUINO_BOARD

#ifdef ARDUINO_BOARD
#define US_0 2
#define US_1 3
#define US_2 4
#define EN_0_A 5
#define EN_0_B 7
#define EN_1_A 8
#define EN_1_B 12
#define MOT_0_A 6
#define MOT_0_B 9
#define MOT_1_A 10
#define MOT_1_B 11
#define LINE_0 A0
#define LINE_1 A1
#define CURR A2
#define I2C_SDA 
#define I2C_SCL 
#endif


#define MOT_IDLE 127
#define SLAVE_ADDRESS 0x50
#define EEPROM_SIZE 21
#define MOTOR_PULSES_PER_ROT 576

enum US_STATE {
  START = 0,
  WAIT = 1,
  DONE = 2,
};

union EncoderU {
  int32_t value = 0;
  uint8_t bytes[4];
};

union LineU {
  uint16_t value = 0;
  uint8_t bytes[2];
};

union CurrentU {
  uint16_t value = 0;
  uint8_t bytes[2];
};


/*
 * Data Space
 * 
 * 0 - US_0 dist [cm] (8b)
 * 1 - US_1 dist [cm] (8b)
 * 2 - US_2 dist [cm] (8b)
 * 3 - encoder_A [-] (32b)
 * 4   ...
 * 5   ...
 * 6   ...
 * 7 - encoder_B [1] (32b)
 * 8   ...
 * 9   ...
 * 10  ...
 * 11 - current probe [-] (2b)
 * 12  ...
 * 13 - line_sens_0 [-] (2b)
 * 14  ...
 * 15 - line_sens_1 [-] (2b)
 * 16  ...
 * 17 - req_motor_0_speed [-] (1b) (0 - full back, 127 - stop, 255 - full forward) / 127 - 0m/s, 128 - 0.01m/s, 255 - 1.28m/s, 0 - -1.27m/s
 * 18 - req_motor_1_speed [-] (1b) (0 - full back, 127 - stop, 255 - full forward)
 * 19 - reserver
 */
 
uint8_t eeprom[EEPROM_SIZE];
uint8_t address = 0;
uint8_t i2c_write_val = 0;

uint8_t us_pins[3] = {US_0, US_1, US_2};
uint8_t us_state = 0;
unsigned long us_start_time = 0;
uint8_t us_index = 0;
const byte us_eeprom_offset = 0;

 
Encoder enc_0(EN_0_A, EN_0_B);
Encoder enc_1(EN_1_A, EN_1_B);
EncoderU en_0, en_1;

LineU line_0;
LineU line_1;
CurrentU curr;

uint8_t l_motor_pwm = 127;
uint8_t r_motor_pwm = 127;

void setup() {

    Serial.begin (115200);
    while (!Serial) {}

    Wire.begin(SLAVE_ADDRESS);
    Wire.onRequest(requestEvent);
    Wire.onReceive(receiveEvent);
    for (int i = 0; i < EEPROM_SIZE; i++) {
        eeprom[i] = 0;
    }
    eeprom[17] = 127; // motors stop
    eeprom[18] = 127;
    motor_task();

    Serial.print("Start\n");
}


void loop() {    
    ultrasound_task();
    encoder_task();
    line_task();
    current_task();
    eeprom_task();
    motor_control_task();
    motor_task();
    
    // delay(1);
    delayMicroseconds(100);
}

// Tasks

void ultrasound_task() {

  uint8_t i = us_index;

  switch (us_state) {
  case US_STATE::START: 

    // Serial.println("S");
    pinMode(us_pins[i], OUTPUT);
    digitalWrite(us_pins[i], LOW);
    delayMicroseconds(2);
    
    digitalWrite(us_pins[i], HIGH);
    delayMicroseconds(10);
    
    digitalWrite(us_pins[i], LOW);
    us_start_time = micros();
    pinMode(us_pins[i], INPUT);
    attachInterrupt(digitalPinToInterrupt(us_pins[i]), on_us, CHANGE);
    us_state = US_STATE::WAIT;
    break;

  case US_STATE::WAIT: 
    // Serial.println("W");
    if (micros() - us_start_time > 10000) { // timeout (about 1m max dist)
      detachInterrupt(digitalPinToInterrupt(us_pins[i]));
      eeprom[us_eeprom_offset + i] = 255;
      us_state = US_STATE::DONE;  
    }
    break;

  case US_STATE::DONE:
    // Serial.println("D");
    us_state = US_STATE::START;
    us_index = (us_index + 1) % 3;
    break;
  }
}

void encoder_task() {
  en_0.value = enc_0.read();
  en_1.value = enc_1.read();
}

void line_task() {
  line_0.value = analogRead(LINE_0);
  line_1.value = analogRead(LINE_1);
}

void current_task() {
  curr.value = analogRead(CURR);
}


void eeprom_task() {
  noInterrupts();

  eeprom[3] = en_0.bytes[3];
  eeprom[4] = en_0.bytes[2];
  eeprom[5] = en_0.bytes[1];
  eeprom[6] = en_0.bytes[0];

  eeprom[7] = en_1.bytes[3];
  eeprom[8] = en_1.bytes[2];
  eeprom[9] = en_1.bytes[1];
  eeprom[10] = en_1.bytes[0];
  
  eeprom[11] = curr.bytes[1];
  eeprom[12] = curr.bytes[0];

  eeprom[13] = line_0.bytes[1];
  eeprom[14] = line_0.bytes[0];

  eeprom[15] = line_1.bytes[1];
  eeprom[16] = line_1.bytes[0];

  interrupts();
}

void motor_task() {
  if (l_motor_pwm < MOT_IDLE) {
        analogWrite(MOT_0_A, 0);
        analogWrite(MOT_0_B, (MOT_IDLE - l_motor_pwm) * 2);
  } else if (l_motor_pwm == MOT_IDLE) {
      analogWrite(MOT_0_A, 0);
      analogWrite(MOT_0_B, 0);
  } else {
      analogWrite(MOT_0_A, (l_motor_pwm - 127) * 2);
      analogWrite(MOT_0_B, 0);
  }

  if (r_motor_pwm < MOT_IDLE) {
      analogWrite(MOT_1_A, 0);
      analogWrite(MOT_1_B, (MOT_IDLE - r_motor_pwm) * 2);
  } else if (r_motor_pwm == MOT_IDLE) {
      analogWrite(MOT_1_A, 0);
      analogWrite(MOT_1_B, 0);
  } else {
      analogWrite(MOT_1_A, (r_motor_pwm - MOT_IDLE) * 2);
      analogWrite(MOT_1_B, 0);
  }
}

class LowPass {
  public:
    LowPass(float coef) : coef_{coef} {}

    float step (float x) {
      val_ = coef_ * val_ + (1.0 - coef_) * x;
      return val_;
    }

  private:
    float val_ = 0;
    float coef_ = 0.0;
};

class Speeder {
  public:
  float step(int32_t encoder, float dt) {
    if (first_) {
      first_ = false;
      last_encoder_ = encoder;
      return 0.0;
    }
    int32_t enc_diff = ((encoder - last_encoder_));
    last_encoder_ = encoder;
    return -((float)(enc_diff)) / dt / MOTOR_PULSES_PER_ROT * 6.28 * 0.033;
  }
  private:
  bool first_ = true;
  float last_encoder_ = 0;
};

class PID {
  public: 
  PID(float p, float i, float d) {
    kp = p;
    ki = i;
    kd = d;
  }

  int8_t step (float speed, float setpoint, float dt) {

    float err = setpoint - speed;

    last_err = err;

    integral += err * dt;
    if (integral * ki > max_output) {
      integral = max_output / ki;
    }
    else if (integral * ki < -max_output) {
      integral = -max_output / ki;
    }

    float deriv = (err - last_err) / dt;
    float output = kp * err + ki * integral + kd * deriv;
    integral *= 0.99;
    return constrain((int)output, -max_output, max_output);
  }
  private:

  float kp = 0.0;
  float ki = 0.0;
  float kd = 0.0;
  float integral = 0.0;
  float last_err = 0.0;
  float max_output = 127;
};

class MotorPipeline {
  
  static constexpr float KP = 4000.0;
  static constexpr float KI = KP * 0.5f; //1000.0;
  static constexpr float KD = KP * 0.25f; //500.0;

  public:
  MotorPipeline() : pid_{KP, KI, KD}, low_pass_(0.9) {}

  float step(int32_t enc, float setpoint, float dt) {
    float spd = speeder_.step(enc, dt);
    float spd_lp = low_pass_.step(spd);
    // Serial.print(setpoint);
    // Serial.print(", ");
    // Serial.print(spd);
    // Serial.print(", ");
    // Serial.print(spd_lp);
    // Serial.print("\n");
    // printf("%f, %f, %f\n", setpoint, spd, spd_lp);
    float output = pid_.step(spd_lp, setpoint, dt);
    return output;
  }

  private:
  Speeder speeder_;
  LowPass low_pass_;
  PID pid_;
};


MotorPipeline mot_pipeline_l;
MotorPipeline mot_pipeline_r;

void motor_control_task() {

  static unsigned long last_time = millis();
  float setpoint_l = float(eeprom[17] - 127) / 100.0; //0.5 * sin(millis()/1000.0); 
  float setpoint_r = float(eeprom[18] - 127) / 100.0; 
  
  unsigned long current_time = millis();
  unsigned long elapsed_time = current_time - last_time;

  if (elapsed_time >= 1) {
    float dt = (float) elapsed_time / 1000.0;

    l_motor_pwm = 127 + mot_pipeline_l.step(en_0.value, -setpoint_l, dt);
    r_motor_pwm = 127 + mot_pipeline_r.step(en_1.value, setpoint_r, dt);
    last_time = current_time;
  }
}


// Interrupts

void on_us() {
  uint8_t i = us_index;
  if(digitalRead(us_pins[i]) == HIGH) {
    us_start_time = micros();
  } else if (digitalRead(us_pins[i]) == LOW) {
    uint8_t distance = (micros() - us_start_time) / 58;
    eeprom[us_eeprom_offset + i] = distance;
    detachInterrupt(digitalPinToInterrupt(us_pins[i]));
      us_state = US_STATE::DONE;  
  }
}


uint8_t i2c_val = 0;

void requestEvent() {
    Wire.write(eeprom[address]);
}


void receiveEvent(int bytes) {
    if (bytes == 1) {
        address = Wire.read();
    } else if (bytes == 2) {
        address = Wire.read();
        eeprom[address] = Wire.read();
    }
}

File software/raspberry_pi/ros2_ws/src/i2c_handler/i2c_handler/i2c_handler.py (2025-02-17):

import time

import rclpy
from rclpy.node import Node

from std_msgs.msg import Empty
from std_msgs.msg import String
from std_msgs.msg import UInt8MultiArray
from std_msgs.msg import UInt16MultiArray
from std_msgs.msg import UInt32MultiArray
from std_msgs.msg import Int32MultiArray
from std_msgs.msg import Float32MultiArray

from sensor_msgs.msg import FluidPressure
from sensor_msgs.msg import Temperature
from sensor_msgs.msg import Imu
from sensor_msgs.msg import MagneticField

from geometry_msgs.msg import Quaternion

import busio
import board
from adafruit_bme280 import basic, advanced as adafruit_bme280
from adafruit_mpu6050 import MPU6050
import adafruit_ads1x15.ads1115 as ADS
from adafruit_ads1x15.analog_in import AnalogIn
import adafruit_ds3231
from RPLCD.i2c import CharLCD

from .arduino import *

ENABLE_ARDUINO = True
ENABLE_BME280 = False
ENABLE_IMU = True
ENABLE_MAG = False
ENABLE_ADC = False
ENABLE_RTC = False
ENABLE_LCD = False
VERBOSE = False



class I2cHandlerNode(Node):
    def __init__(self):
        super().__init__('i2c_handler')

        self.frame = "/bpc_prp_robot"
        self.i2c = busio.I2C(board.SCL, board.SDA)

        self.motor_watchdog = 0
        self.motor_watchdog_timer = self.create_timer(0.1, self.on_motor_watchdog)

        if ENABLE_ARDUINO:
            self.arduino = Arduino(self.i2c)
            self.ultrasounds_publisher = self.create_publisher(UInt8MultiArray, '/bpc_prp_robot/ultrasounds', 0)
            self.line_sensors_publisher = self.create_publisher(UInt16MultiArray, '/bpc_prp_robot/line_sensors', 0)
            self.current_probes_publisher = self.create_publisher(UInt16MultiArray, '/bpc_prp_robot/current_probes', 0)
            self.encoders_publishers = self.create_publisher(UInt32MultiArray, '/bpc_prp_robot/encoders', 0)
            self.motor_speeds_subscriber = self.create_subscription(UInt8MultiArray, '/bpc_prp_robot/set_motor_speeds',
                                                                    self.on_set_motor_speeds, 0)
            self.arduino_slow_timer = self.create_timer(0.2, self.on_arduino_slow)
            self.arduino_fast_timer = self.create_timer(0.01, self.on_arduino_fast)

        if ENABLE_BME280:
            self.bme280 = adafruit_bme280.Adafruit_BME280_I2C(self.i2c, 118)
            self.bme280.sea_level_pressure = 1013.25

            self.bme280.mode = adafruit_bme280.MODE_NORMAL
            self.bme280.standby_period = adafruit_bme280.STANDBY_TC_0_5
            self.bme280.iir_filter = adafruit_bme280.IIR_FILTER_X16
            self.bme280.overscan_pressure = adafruit_bme280.OVERSCAN_X1
            self.bme280.overscan_humidity = adafruit_bme280.OVERSCAN_X1
            self.bme280.overscan_temperature = adafruit_bme280.OVERSCAN_X1

            self.press_publisher = self.create_publisher(FluidPressure, '/bpc_prp_robot/air_press', 0)
            self.temp_publisher = self.create_publisher(Temperature, '/bpc_prp_robot/temp', 0)

            self.bme_280_timer = self.create_timer(0.1, self.on_bme280)

        if ENABLE_IMU:
            self.mpu = MPU6050(self.i2c, 105)
            self.imu_publisher = self.create_publisher(Imu, '/bpc_prp_robot/imu', 0)
            self.imu_timer = self.create_timer(0.01, self.on_imu)

        if ENABLE_MAG:
            self.mag_publisher = self.create_publisher(MagneticField, '/bpc_prp_robot/mag', 0)
            self.mag_timer = self.create_timer(0.1, self.on_mag)

        if ENABLE_IMU or ENABLE_MAG:
            pass

        if ENABLE_ADC:
            self.ads = ADS.ADS1115(self.i2c)
            self.ads_channel0 = AnalogIn(self.ads, ADS.P0)
            self.ads_channel1 = AnalogIn(self.ads, ADS.P1)
            self.ads_channel2 = AnalogIn(self.ads, ADS.P2)
            self.ads_channel3 = AnalogIn(self.ads, ADS.P3)
            self.adc_publisher = self.create_publisher(Float32MultiArray, '/bpc_prp_robot/adc', 0)
            self.ads_timer = self.create_timer(0.1, self.on_ads)

        if ENABLE_RTC:
            self.rtc = adafruit_ds3231.DS3231(self.i2c)
            self.time_publisher = self.create_publisher(Int32MultiArray, '/bpc_prp_robot/time', 0)
            self.time_subscriber = self.create_subscription(Int32MultiArray, '/bpc_prp_robot/set_time',
                                                            self.on_set_time, 0)
            self.ds3231 = self.create_timer(1, self.on_ds3231)

        if ENABLE_LCD:
            self.lcd = CharLCD(i2c_expander='PCF8574', address=0x27, port=1, cols=20, rows=4, dotsize=8)
            self.lcd_text_subscriber = self.create_subscription(String, '/bpc_prp_robot/set_lcd_text',
                                                                self.on_set_lcd_text, 0)
            self.lcd_cursor_subscriber = self.create_subscription(UInt8MultiArray, '/bpc_prp_robot/set_lcd_cursor',
                                                                  self.on_set_lcd_cursor, 0)
            self.lcd_clear = self.create_subscription(Empty, '/bpc_prp_robot/set_lcd_clear', self.on_set_lcd_clear, 0)

        print("Init done")

    def on_arduino_slow(self):
        us_msg = UInt8MultiArray()
        us_msg.data.append(self.arduino.ultrasound_0())
        us_msg.data.append(self.arduino.ultrasound_1())
        us_msg.data.append(self.arduino.ultrasound_2())
        self.ultrasounds_publisher.publish(us_msg)

        current_msg = UInt16MultiArray()
        current_msg.data.append(self.arduino.current())
        self.current_probes_publisher.publish(current_msg)

    def on_arduino_fast(self):
        line_sensors_msg = UInt16MultiArray()
        ls_0 = self.arduino.line_sensor_0()
        ls_1 = self.arduino.line_sensor_1()
        line_sensors_msg.data.append(ls_0)
        line_sensors_msg.data.append(ls_1)
        self.line_sensors_publisher.publish(line_sensors_msg)

        en_a = self.arduino.encoder_a()
        en_b = self.arduino.encoder_b()
        encoder_msg = UInt32MultiArray()
        encoder_msg.data.append(en_a)
        encoder_msg.data.append(en_b)
        self.encoders_publishers.publish(encoder_msg)
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

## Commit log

2024-11-25 added 3d print components
    [ar_tag_plate.STL, battery_mount.STL, camera_mount.STL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]
2024-11-25 added pcbs
    [BPC-PRP-i2c-board.kicad_pcb, BPC-PRP-i2c-board.kicad_sch, BPC-PRP-microcontroller.kicad_pcb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]
2024-11-25 added overall schematics
2024-11-25 updated readme and overview schematics
2024-11-26 add arduino firmware
2024-11-26 add power supply schematic
2024-11-28 updated rpi ext board
    [BPC-PRP-rpi-hat.kicad_pcb, BPC-PRP-rpi-hat.kicad_sch]
2024-11-28 updated arduino board, add leds
    [BPC-PRP-microcontroller.kicad_pcb, BPC-PRP-microcontroller.kicad_sch]
2024-11-28 minor update i2c board, added pdbs schematics and renders
    [BPC-PRP-i2c-board.kicad_pcb]
2024-11-28 added wheel.stl for 3d print
    [wheel.STL]
2024-12-01 add wiring diagram
2024-12-01 add i2c pullups for rpi ext and i2c board
    [BPC-PRP-i2c-board.kicad_pcb, BPC-PRP-i2c-board.kicad_sch, BPC-PRP-rpi-hat.kicad_pcb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]
2024-12-01 added draw io wirign schema
2024-12-02 updated srf05 holder, whee, added ball and pillar
    [ball_2.STL, pillar.STL, srf05_mount.STL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]
2024-12-03 add arduino tutorial
2025-01-05 add wiring table
2025-01-05 update wiring picture
2025-01-05 update wiring schema drawio file
2025-01-13 updated arduino code
2025-02-03 Rpi install (#1)
    * Repair intendation
    * Installation scripts
    * Change services, mostly paths
    * Tested on clean system
    * Change legacy mode for camera
    * Guide and test on clean sd card
    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
2025-02-05 add assembly documentation
2025-02-08 updated arduino sw
2025-02-17 updated imu
2025-10-13 updated book. added sw description and hw bom, modules and wiring
2025-10-14 wiring hotfix
2025-10-14 bom hotfix
2025-10-14 arduino text hotfix
2026-05-19 Add CLAUDE.md guide for Claude Code
    Repo-level guidance: two-tier Pi/Arduino architecture, /bpc_prp_robot/* ROS 2 topic map, build/launch commands, provisioning scripts, mdBook docs structure.
2026-05-19 Fix rgb_leds_handler node name (T1.9)
    RgbLedsHandlerNode was initializing itself as 'camera_handler', so 'ros2 node list' and any tooling that finds nodes by name would mismatch the actual LED handler. Use 'rgb_leds_handler' to match the package and file name.
    Verified: python3 -m py_compile succeeds. A full ROS 2 runtime test would require an actual robot with the neopixel/board libraries available.
    [rgb_leds_handler.py]
2026-05-19 Update CLAUDE.md: precise camera topic description
    Clarify the camera_handler_cpp row in the Pi ROS 2 nodes table: the publisher advertises base topic /bpc_prp_robot/camera as sensor_msgs/Image (bgr8) via image_transport with the 'compressed' transpo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
2026-05-20 CLAUDE.md: PARK modernization branches until end of semester
    The BPC-PRP course is currently in session and runs against this
    robot. Add a prominent PARKED notice to the branch-state section.
    Also:
    * Update unpushed/unpushed -> pushed-to-origin for both feature
    branches (they were pushed 2026-05-20).
    * Record commit ranges (3 / 4 commits ahead of main).
    * Fix the GCC-version reference (was "GCC 14", actually GCC 13.3
    on Ubuntu 24.04 -- caught in the T3.1 smoke test).
    * Pointer to the pre-drafted PR description in
    bpc-prp-devel/MODERNIZATION_ROADMAP.md Appendix C (Merge 4/5).
2026-05-27 Post-merge cleanup: lift PARK notice (Merge 4 landed 2026-05-27)
    Updates the "Branch state" callout: main now carries the
    rgb_leds_handler node-name fix (T1.9) and Phase 3 prep notes from
    the merged modernization/phase-1 + modernization/phase-3 branches.
    modernization/phase-4 (the fenrir_sim Gazebo package) remains
    unmerged — waits on T4.3 ultrasound/button/RGB-LED bridges before
    Merge 6. T3.3 robot-runtime image is still blocked on T2.1.
